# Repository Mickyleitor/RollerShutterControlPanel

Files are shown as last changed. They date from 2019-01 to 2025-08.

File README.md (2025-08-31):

# Roller Shutter Control Panel

Embedded wall panel for motorized shutters over radio; with LCD; buttons; Wi-Fi via ESP8266; clock;
and temperature. Open hardware with 3D-printed parts; off-the-shelf modules; and a PCB using an
ATMega328P plus ESP8266.

<p align="center">
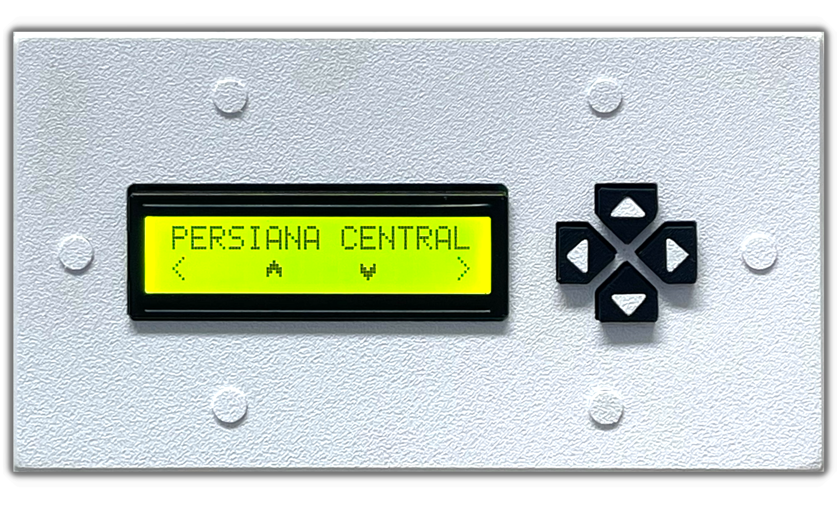
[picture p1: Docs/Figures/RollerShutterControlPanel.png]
  
</p>

## Motivation and origins

Built to stop sunrise from waking me early; first a simple wall controller; then my 2020 Bachelor’s
thesis; now an open build others can replicate; learn from; and adapt. Also a testbed for new ideas.

## Project status; what it does today

Actively used and stable. Local controller for **three** shutters; buttons to move; LCD for time and
date; current temperature from the internet; on-device Wi-Fi setup; ESP8266 firmware updates over
the air. No cloud required.

## Current functionality

- **Three shutters**; Left; Center; Right; actions: Up; Down; Stop at any time.
- **16×2 I²C LCD**; Shutter management, clock on idle and configuration menu.
- **Current temperature**; periodic OpenWeatherMap request; hides value when unavailable.
- **On-device Wi-Fi setup**; scan networks; choose SSID; enable or disable Wi-Fi and OTA;
- **Auto reconnect**; for both wifi attemps and weather requests.
- **Time and timezone editor**; set time and timezone.
- **OTA updates** for the ESP8266 using ArduinoOTA; handled in the background.
- **Buzzer feedback**; adjustable volume; enable or disable; accept and error tones.
- **Debug pages**; soft reset counter; current SSID with link status; device IP.

## Repository layout

```
Docs/                     Documents
├─ Figures/               Diagrams, schematics, screenshots
├─ Files/                 Raw docs (.docx, .pdf, etc.)
└─ Photos/                Prototyping photos

Firmware_Arduino/         Arduino MCU source
Firmware_ESP8266/         ESP8266 source
Firmware_Processing_HCI/  Processing-IDE files

PCB_Design/               KiCAD board files
├─ Libraries/             Custom symbols
└─ Modules/               Footprints & 3D models

3D_Design/                Panel case models
```

## Tools

Free or evaluation to avoid licensing issues:  
• KiCAD; Arduino IDE; Google SketchUp (free); GIMP; Cameo Systems Modeler (evaluation);  
  draw.io (online); VSCode.

## License

CERN Open Hardware Licence.

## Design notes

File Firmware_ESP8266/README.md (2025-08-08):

# Roller Shutter Control Panel — Main CPU (ESP8266)

This serves as the primary CPU for the roller shutter control panel; it uses the [ESP8266]
microcontroller and is programmed using the [Arduino IDE].

## Introduction

This firmware runs on an ESP8266 module and acts as the “brain” of a roller shutter control panel.
It drives a 16x2 I²C LCD; reads panel buttons; and commands three shutters through a radio module
via I²C. When Wi-Fi is enabled it connects as a station; fetches the current temperature and the
timezone shift; keeps the clock in sync; and shows status on the LCD. All common settings can be
changed from the panel; no reflash required.

## Proposed Enhancements

1. **AP fallback for first-time setup.** If repeated station connects fail; bring up a temporary AP
   and a tiny config page; go back to STA when saved.
2. **Location and API key in UI.** Add menu items to edit OpenWeatherMap `lat` and `lon` and rotate
   the API key; mask the key in the UI; store in EEPROM.
3. **HTTPS for the web UI** start with a self-signed cert; allow uploading a new certificate for
   encrypted credentials.
4. **Language option** Keep Spanish strings; add English selection in a simple Language menu.
5. **Update radio-module** Update radio-module firmware from ESP8266; and from the web UI or OTA.
6. **Diagnostics** Optional web pages to visualize additional data when it adds value.

[ESP8266]: https://en.wikipedia.org/wiki/ESP8266
[Arduino IDE]: https://www.arduino.cc/en/Main/Software

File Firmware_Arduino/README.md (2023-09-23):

# Roller Shutter Control Panel Slave CPU

The Roller Shutter Control Panel Slave CPU is a vital component of the larger Domotic Shutter Control System. It operates as an ATmega368P microcontroller, serving as a subordinate CPU within the system.

## Overview

This CPU is dedicated to interfacing with the primary control unit (main CPU) using the I2C communication protocol as the physical layer. However, the communication between the main CPU and the slave CPU relies on the RSCP (Roller Shutter Control Panel) stack protocol. Its primary function is to receive commands and data from the main CPU via the RSCP protocol and execute various control tasks related to roller shutter operation, relay switching, and buzzer control.

## Key Features

- **RSCP Protocol**: The slave CPU communicates with the main CPU using the RSCP (Roller Shutter Control Panel) stack protocol that is implemented on top of the I2C physical layer.

- **Roller Shutter Control**: It possesses the capability to command the movement of roller shutters, including actions such as opening, closing, and stopping.

- **Relay Switching**: The CPU has the capability to control relays, enabling the activation or deactivation of connected devices or circuits.

- **Buzzer Control**: The inclusion of buzzer control functionality allows for audible alerts or notifications.

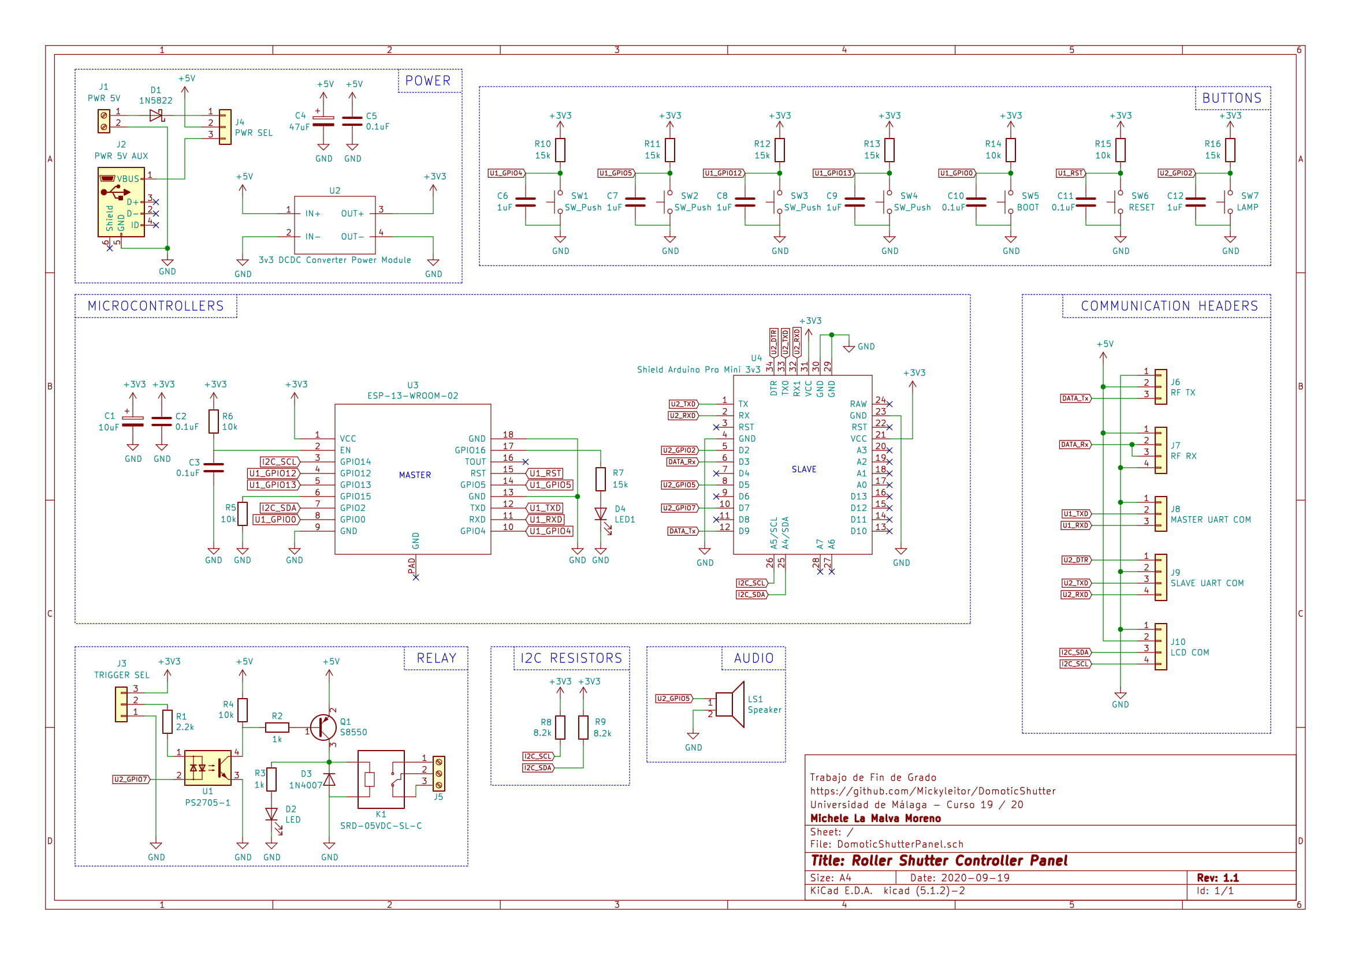
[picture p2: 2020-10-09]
Docs/Figures/RollerShutterControlPanel_Schematic.jpg

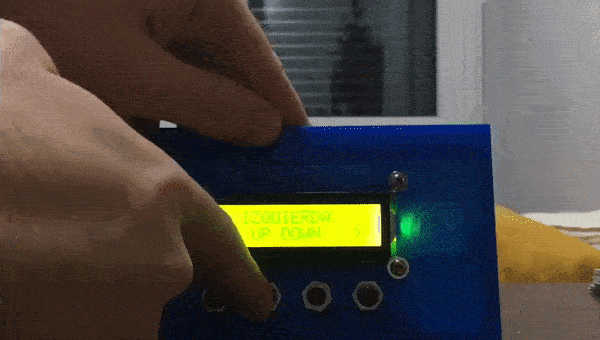
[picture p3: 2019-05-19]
Docs/Photos/Demo2.gif

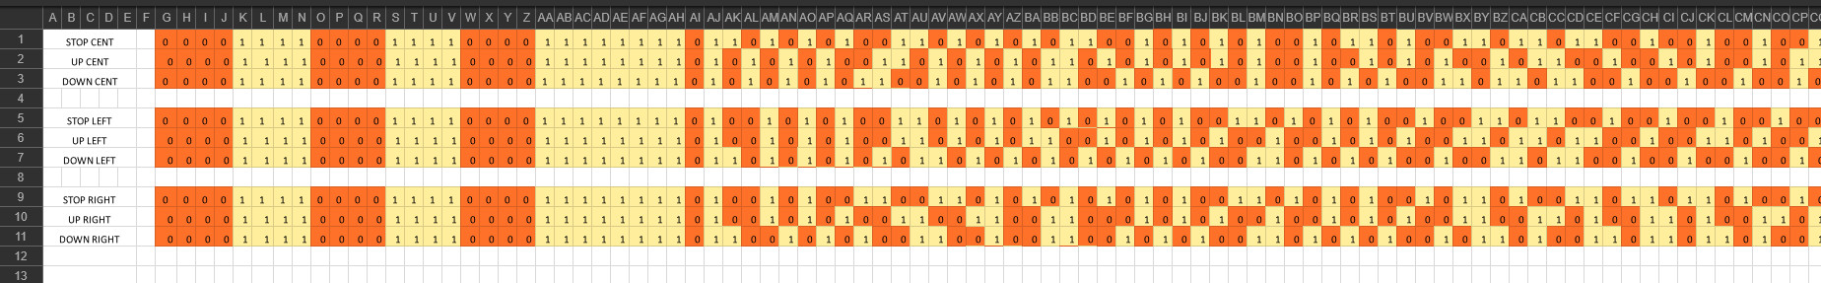
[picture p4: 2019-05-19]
Docs/Photos/Excelmessages.jpg

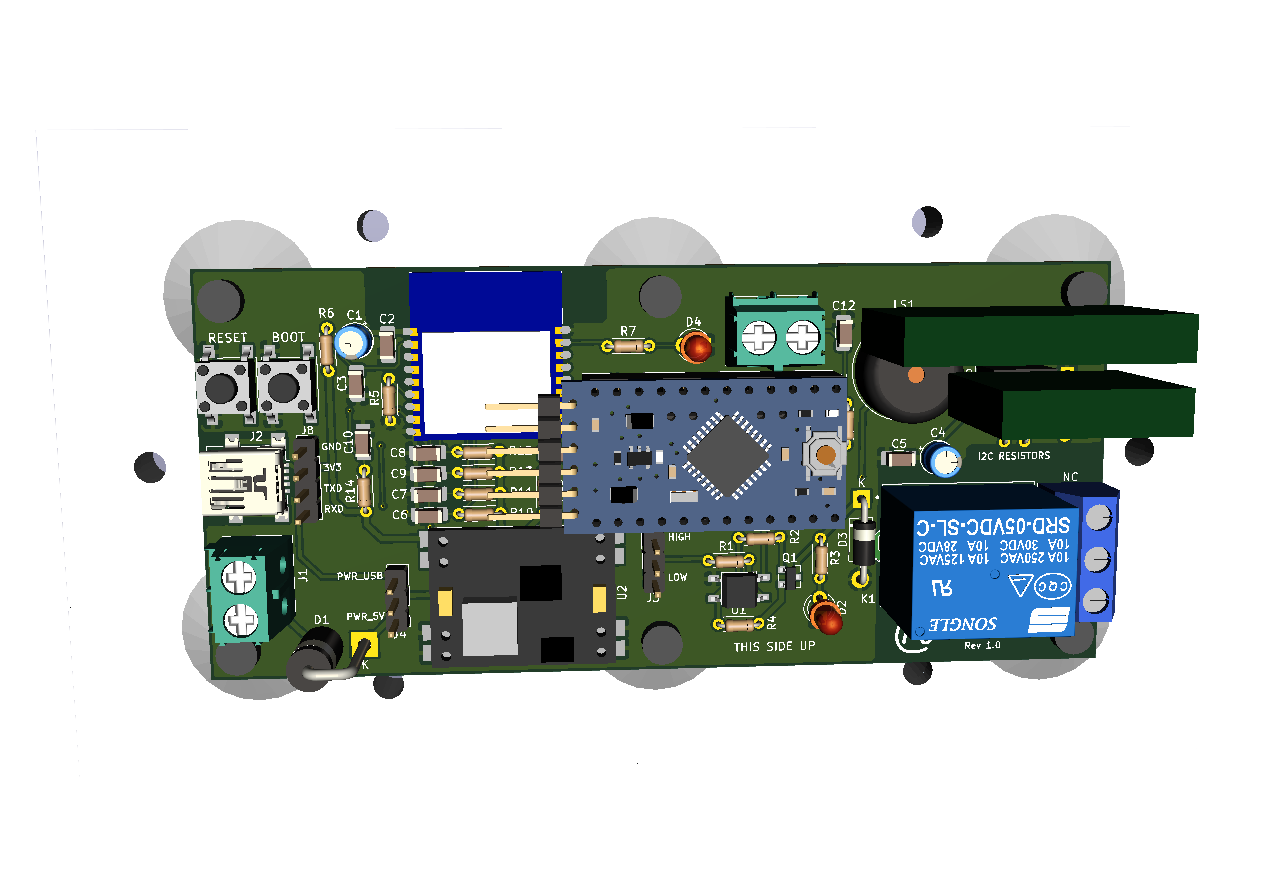
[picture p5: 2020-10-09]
Docs/Figures/RollerShutterControl3D.png

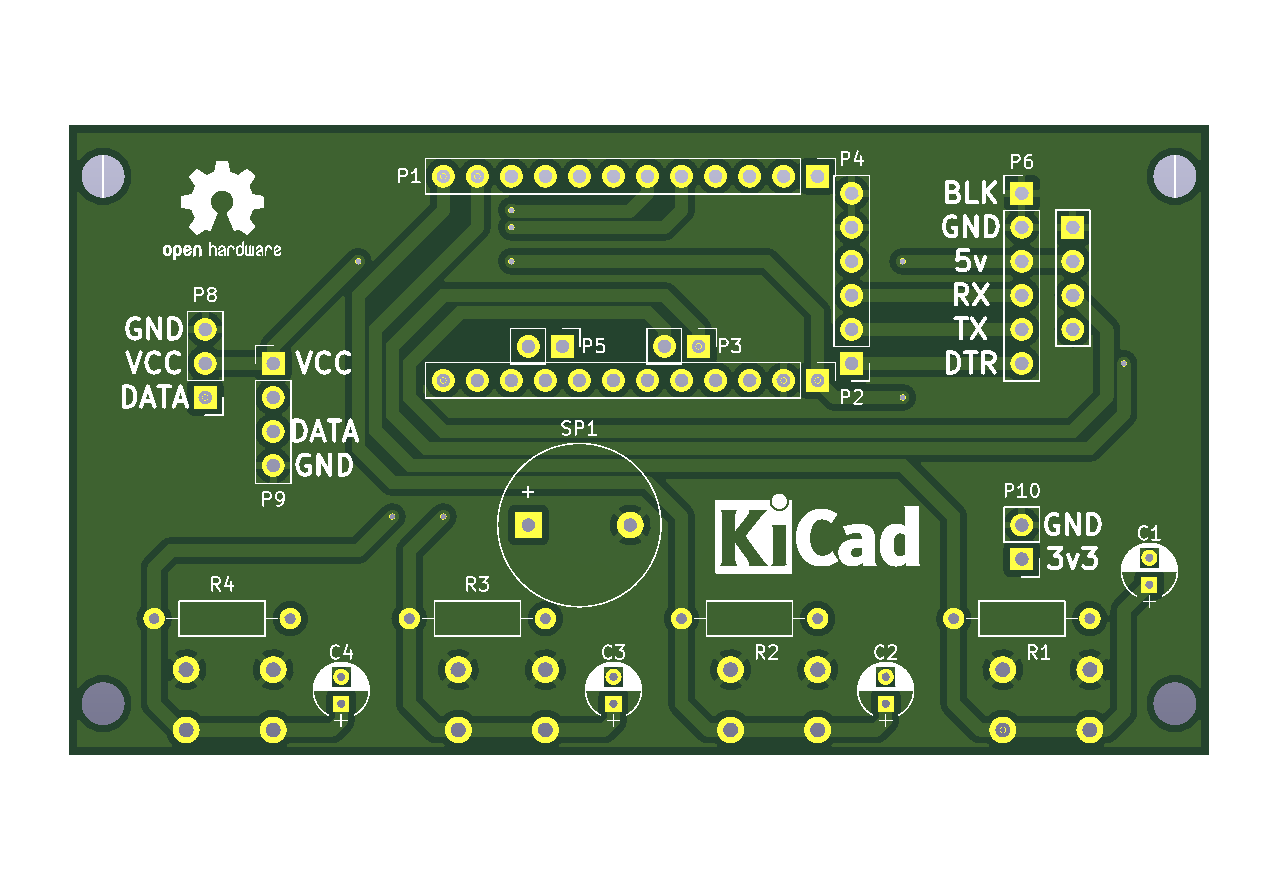
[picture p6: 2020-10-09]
Docs/Figures/RollerShutterControlBoardFront_v1.png

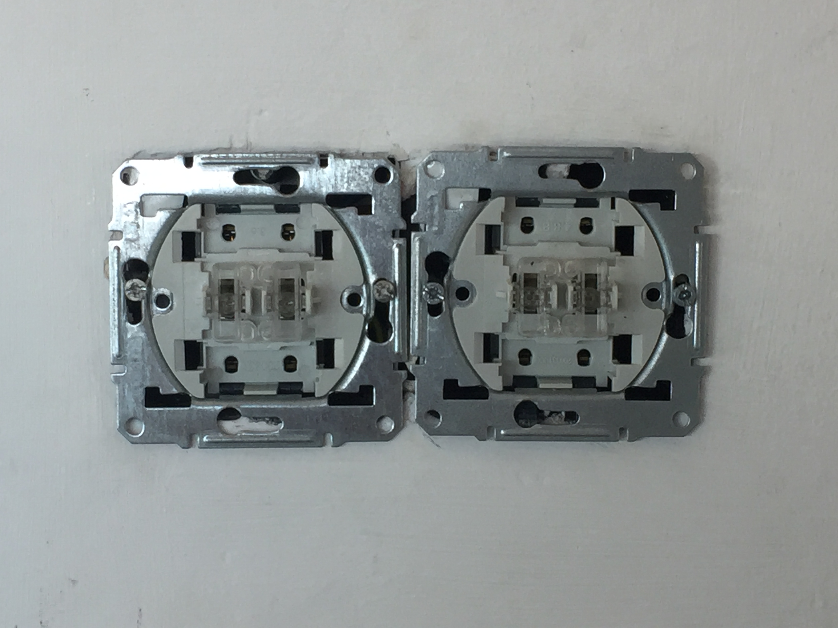
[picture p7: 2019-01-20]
Docs/Photos/EmpotradoPared1.JPG

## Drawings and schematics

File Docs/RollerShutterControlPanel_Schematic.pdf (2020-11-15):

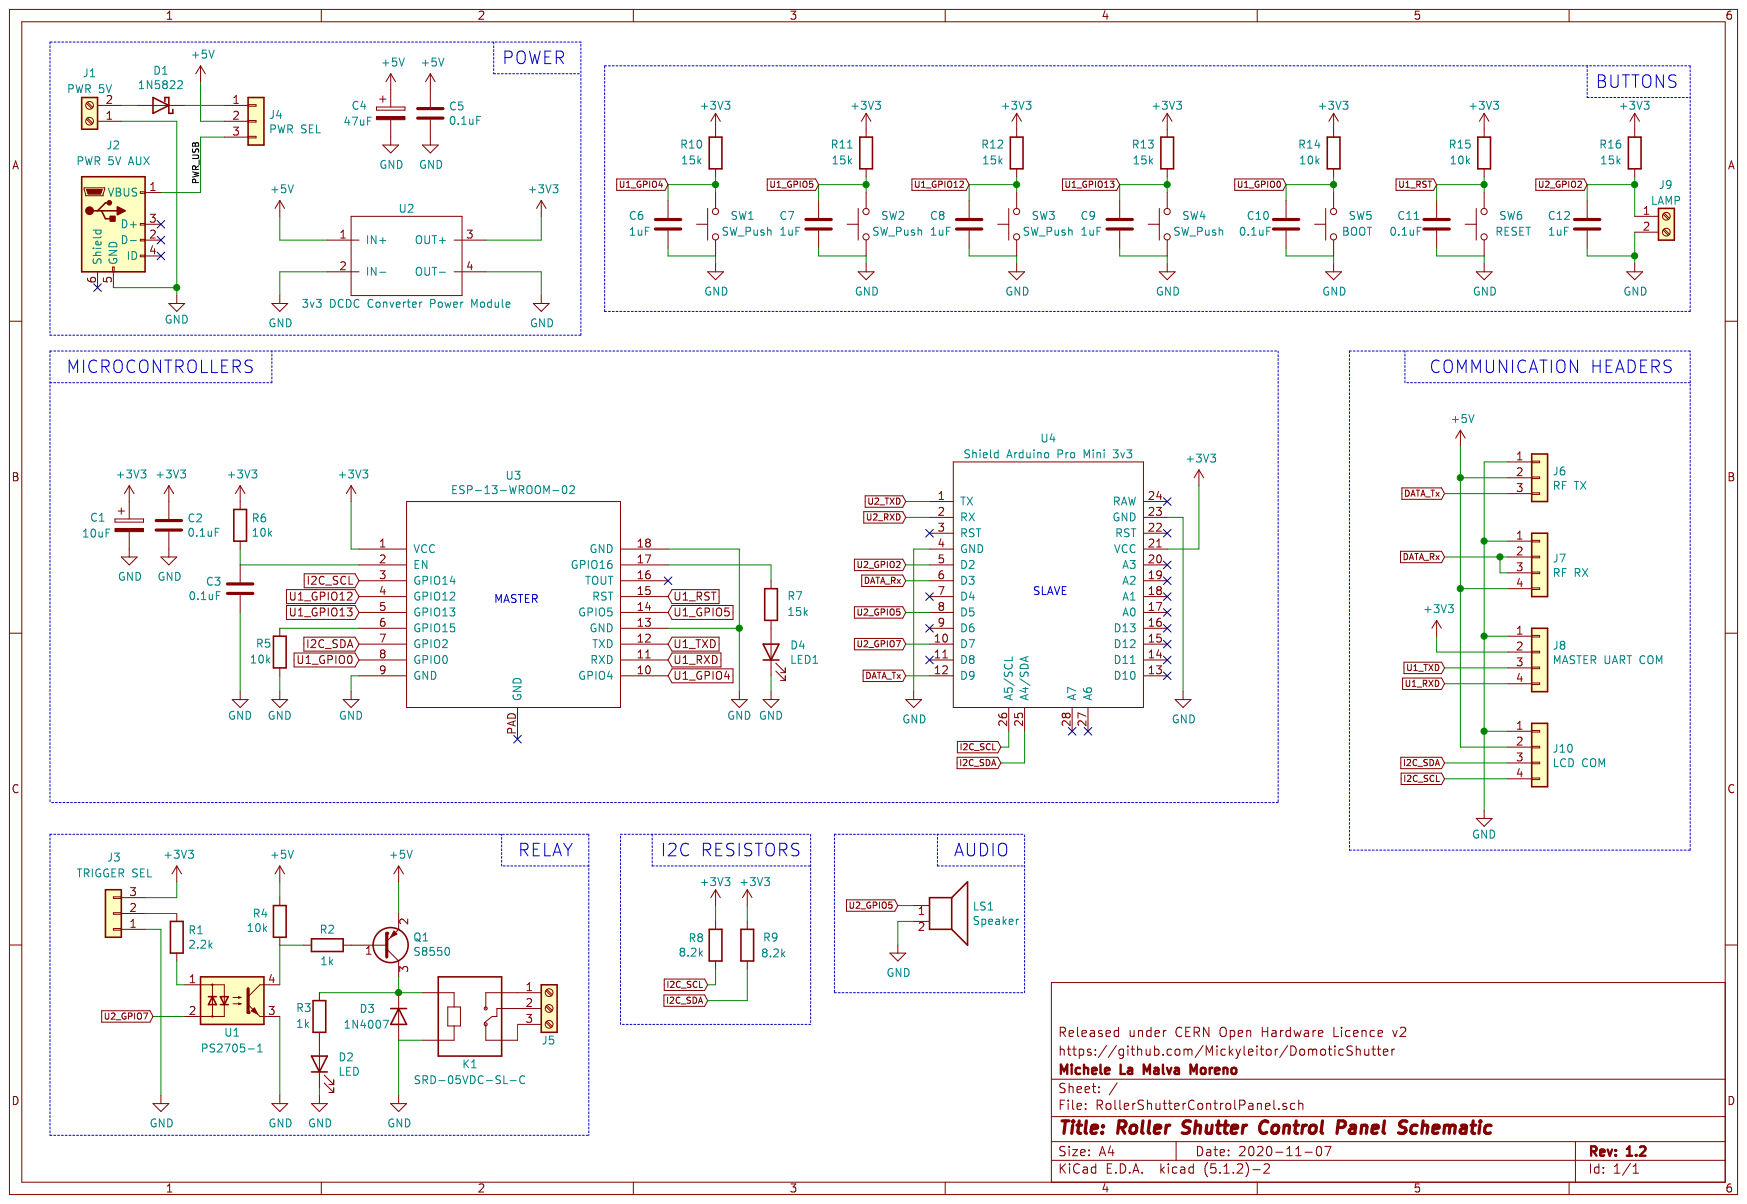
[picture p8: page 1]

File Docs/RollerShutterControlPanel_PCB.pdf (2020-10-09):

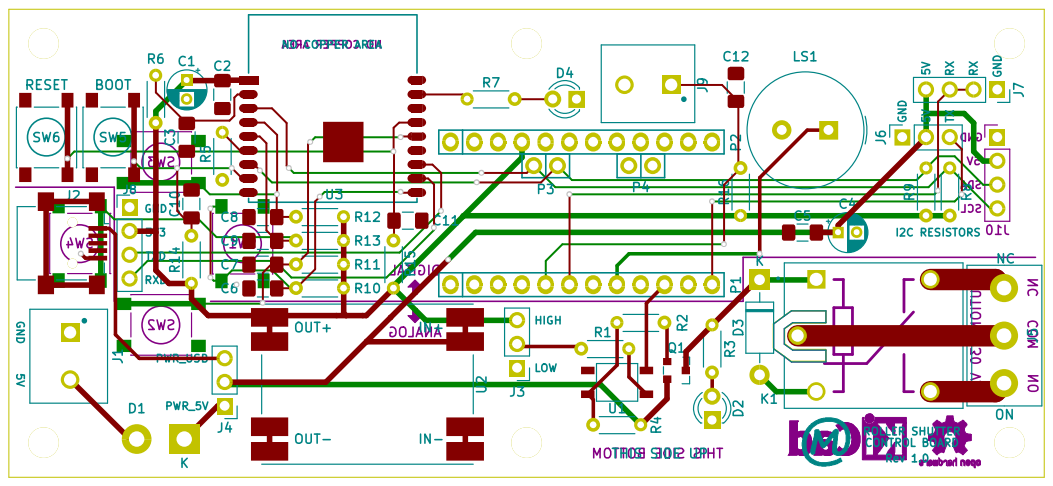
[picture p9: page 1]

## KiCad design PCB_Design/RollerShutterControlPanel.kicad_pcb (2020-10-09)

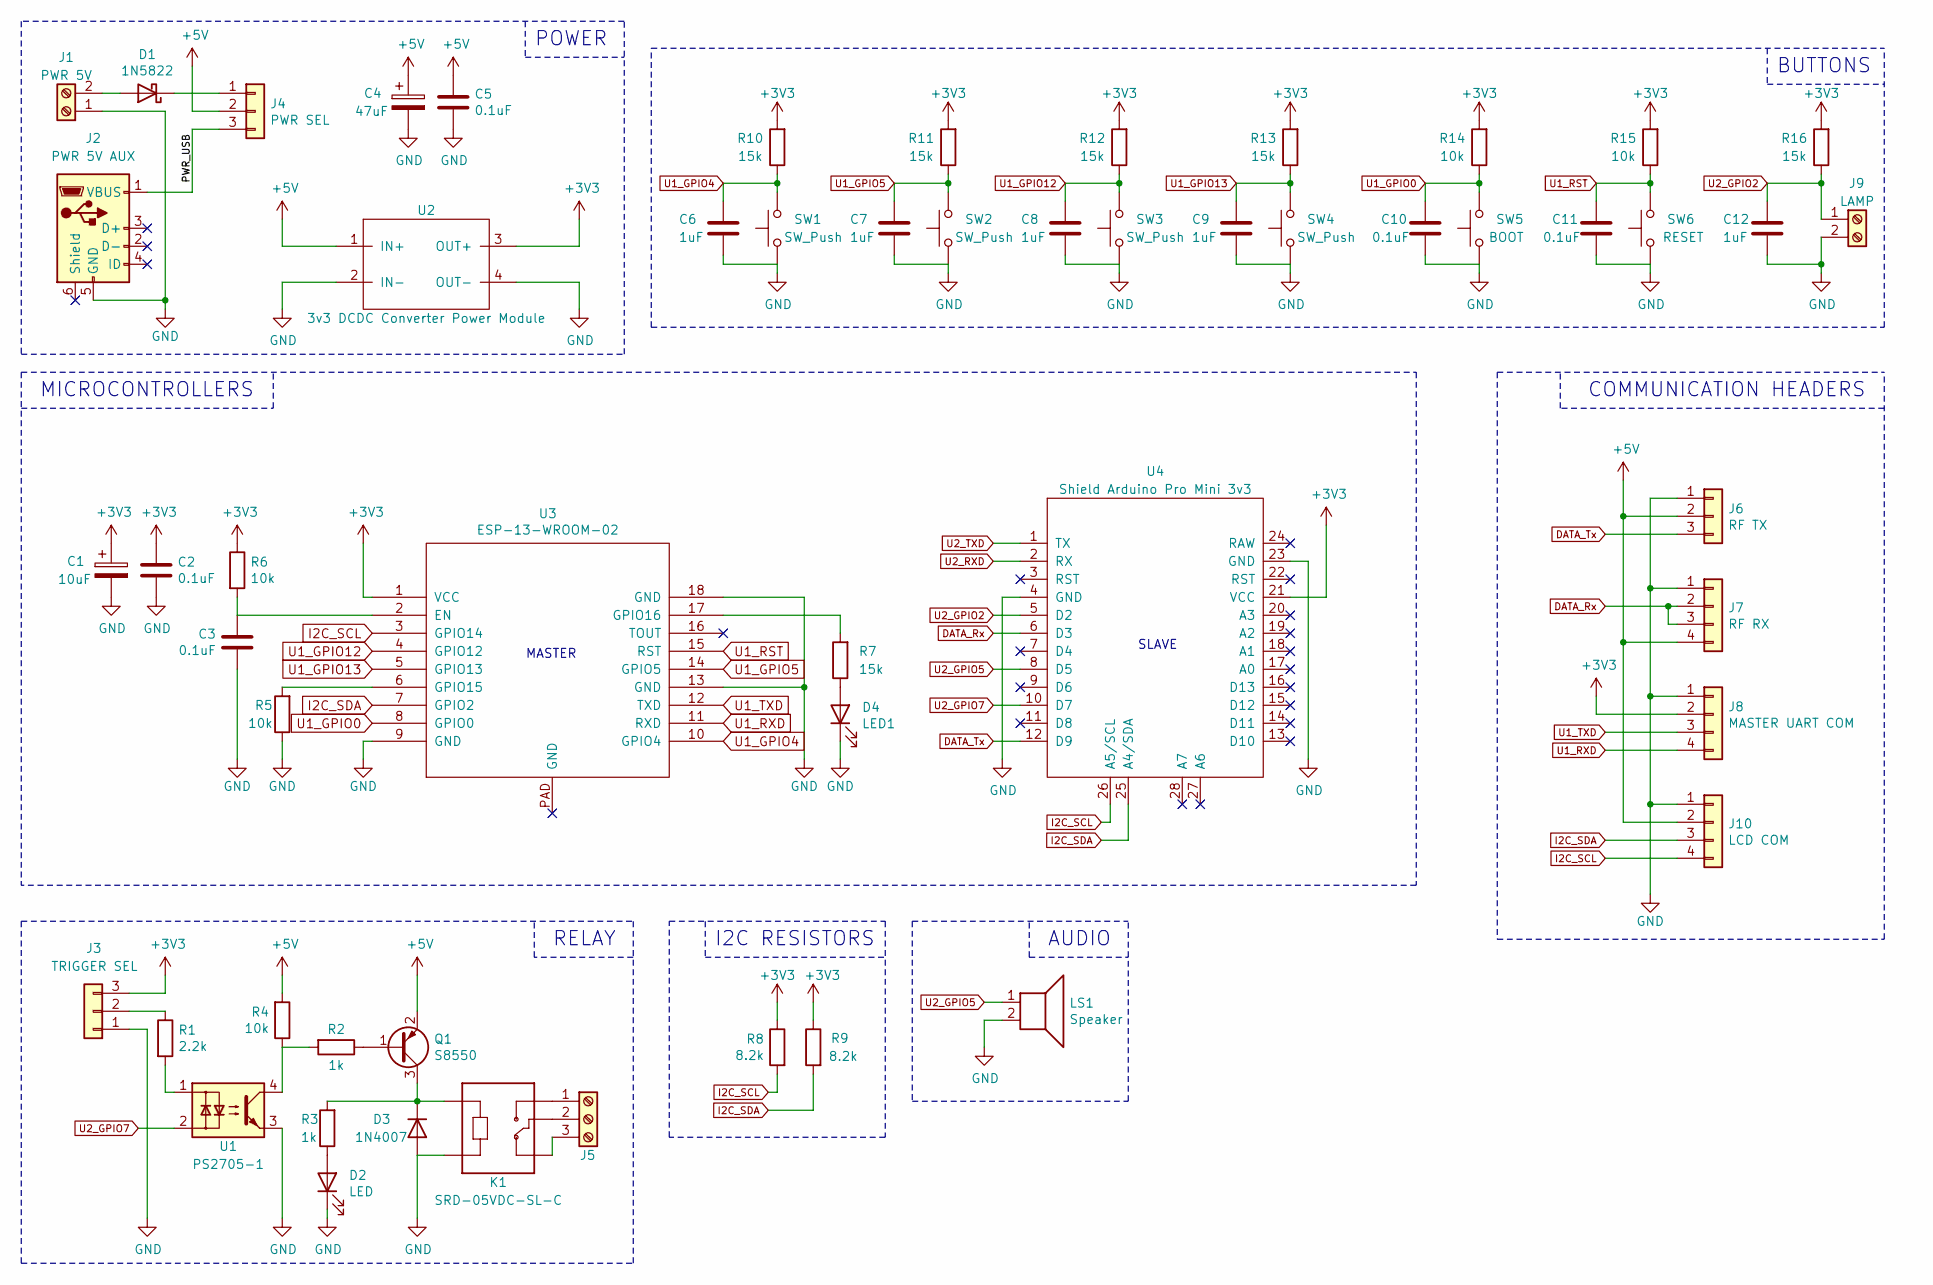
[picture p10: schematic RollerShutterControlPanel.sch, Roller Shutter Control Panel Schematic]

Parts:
C1: 10uF; CP_Radial_D4.0mm_P2.00mm
C2, C3, C5, C10, C11: 0.1uF; C_1206_3216Metric_Pad1.42x1.75mm_HandSolder
C4: 47uF; CP_Radial_D4.0mm_P2.00mm
C6, C7, C8, C9, C12: 1uF; C_1206_3216Metric_Pad1.42x1.75mm_HandSolder
D1: 1N5822; D_DO-201AD_P5.08mm_Vertical_KathodeUp
D2: LED; LED_D3.0mm
D3: 1N4007; D_DO-41_SOD81_P10.16mm_Horizontal
D4: LED1; LED_D3.0mm
J1: PWR 5V; PHOENIX_1935161
J2: PWR 5V AUX; USB_Mini-B_Lumberg_2486_01_Horizontal
J3: TRIGGER SEL; PinHeader_1x03_P2.54mm_Vertical
J4: PWR SEL; PinHeader_1x03_P2.54mm_Vertical
J5: Screw_Terminal_01x03; ScrewTerminal_01X03_5mm
J6: RF TX; PinSocket_1x03_P2.54mm_Vertical
J7: RF RX; PinSocket_1x04_P2.54mm_Vertical
J8: MASTER UART COM; PinHeader_1x04_P2.54mm_Vertical
J9: LAMP; PHOENIX_1935161
J10: LCD COM; PinSocket_1x04_P2.54mm_Vertical
K1: SRD-05VDC-SL-C; RELAY_SRD-05VDC-SL-C
LS1: Speaker; Buzzer_TDK_PS1240P02BT_D12.2mm_H6.5mm
Q1: S8550; SOT-23_S8550
R1: 2.2k; R_Axial_DIN0204_L3.6mm_D1.6mm_P5.08mm_Horizontal
R2, R3: 1k; R_Axial_DIN0204_L3.6mm_D1.6mm_P5.08mm_Horizontal
R4, R5, R6, R14, R15: 10k; R_Axial_DIN0204_L3.6mm_D1.6mm_P5.08mm_Horizontal
R7, R10, R11, R12, R13, R16: 15k; R_Axial_DIN0204_L3.6mm_D1.6mm_P5.08mm_Horizontal
R8, R9: 8.2k; R_Axial_DIN0204_L3.6mm_D1.6mm_P5.08mm_Horizontal
SW1, SW2, SW3, SW4: SW_Push; SW_Push_1P1T_NO_6x6mm_H5mm
SW5: BOOT; SW_Push_1P1T_NO_6x6mm_H5mm
SW6: RESET; SW_Push_1P1T_NO_6x6mm_H5mm
U1: PS2705-1; PS2705-1-F3
U2: 3v3 DCDC Converter Power Module; DCDC_3v3_PowerModule
U3: ESP-13-WROOM-02
U4: Shield Arduino Pro Mini 3v3; Socket_Strip_Arduino_MiniPro

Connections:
+3V3: C1.1, C2.1, J3.3, J8.2, R6.1, R8.1, R9.1, R10.2, R11.2, R12.2, R13.2, R14.2, R15.2, R16.2, U2.3 (OUT+), U3.1 (VCC), U4.21 (VCC)
+5V: C4.1, C5.1, J4.2, J6.2, J7.4, J10.2, Q1.2 (E), R4.2, U2.1 (IN+)
/PWR_USB: J2.1 (VBUS), J4.3
DATA_Rx: J7.2, J7.3, U4.6 (D3)
DATA_Tx: J6.3, U4.12 (D9)
GND: C1.2, C2.2, C3.2, C4.2, C5.2, C6.1, C7.1, C8.1, C9.1, C10.1, C11.1, C12.1, D2.1 (K), D3.2 (A), D4.1 (K), J1.1, J2.5 (GND), J3.1, J6.1, J7.1, J8.1, J9.2, J10.1, K1.A2, LS1.2, R5.1, SW1.1, SW2.1, SW3.1, SW4.1, SW5.1, SW6.1, U1.3, U2.2 (IN-), U2.4 (OUT-), U3.9 (GND), U3.13 (GND), U3.18 (GND), U4.4 (GND), U4.23 (GND)
I2C_SCL: J10.4, R8.2, U3.3 (GPIO14), U4.26 (A5/SCL)
I2C_SDA: J10.3, R9.2, U3.7 (GPIO2), U4.25 (A4/SDA)
unnamed: C3.1, R6.2, U3.2 (EN)
unnamed: D1.1 (K), J4.1
unnamed: D1.2 (A), J1.2
unnamed: D2.2 (A), R3.1
unnamed: D3.1 (K), K1.A1, Q1.3 (C), R3.2
unnamed: D4.2 (A), R7.1
unnamed: J3.2, R1.1
unnamed: J5.1, K1.NO
unnamed: J5.2, K1.COM
unnamed: J5.3, K1.NC
unnamed: Q1.1 (B), R2.1
unnamed: R1.2, U1.1
unnamed: R2.2, R4.1, U1.4
unnamed: R5.2, U3.6 (GPIO15)
unnamed: R7.2, U3.17 (GPIO16)
U1_GPIO0: C10.2, R14.1, SW5.2, U3.8 (GPIO0)
U1_GPIO4: C6.2, R10.1, SW1.2, U3.10 (GPIO4)
U1_GPIO5: C7.2, R11.1, SW2.2, U3.14 (GPIO5)
U1_GPIO12: C8.2, R12.1, SW3.2, U3.4 (GPIO12)
U1_GPIO13: C9.2, R13.1, SW4.2, U3.5 (GPIO13)
U1_RST: C11.2, R15.1, SW6.2, U3.15 (RST)
U1_RXD: J8.4, U3.11 (RXD)
U1_TXD: J8.3, U3.12 (TXD)
U2_GPIO2: C12.2, J9.1, R16.1, U4.5 (D2)
U2_GPIO5: LS1.1, U4.8 (D5)
U2_GPIO7: U1.2, U4.10 (D7)
U2_RXD: U4.2 (RX)
U2_TXD: U4.1 (TX)

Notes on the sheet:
I2C RESISTORS
AUDIO
SLAVE
MASTER
COMMUNICATION HEADERS
RELAY
MICROCONTROLLERS
BUTTONS
POWER

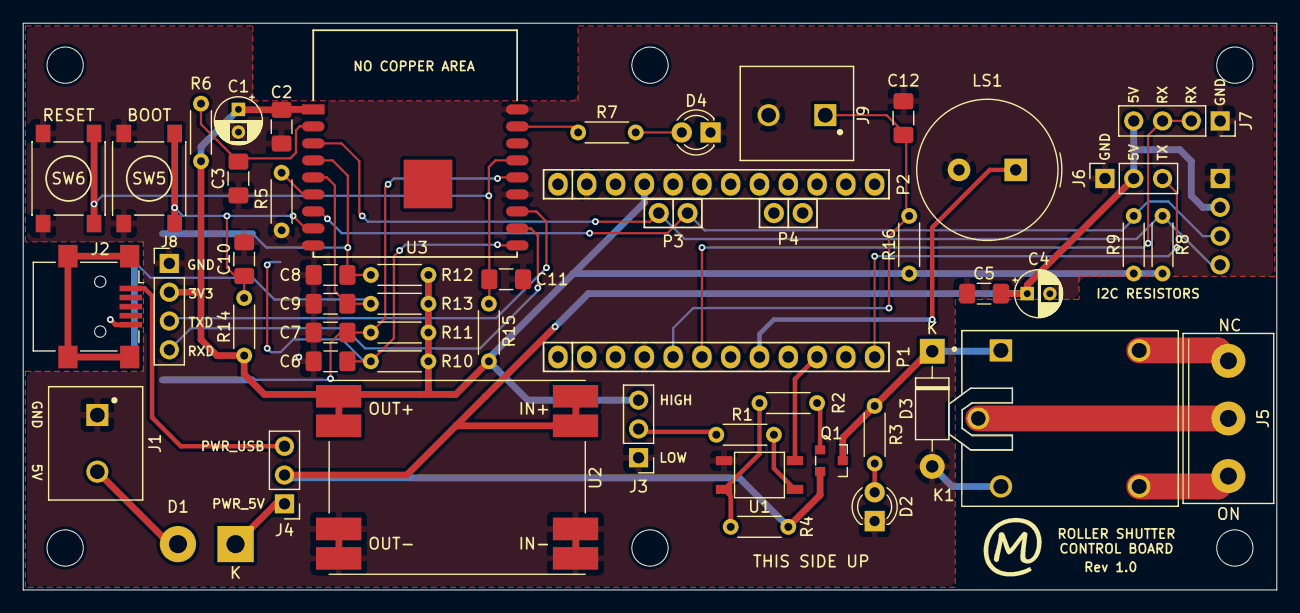
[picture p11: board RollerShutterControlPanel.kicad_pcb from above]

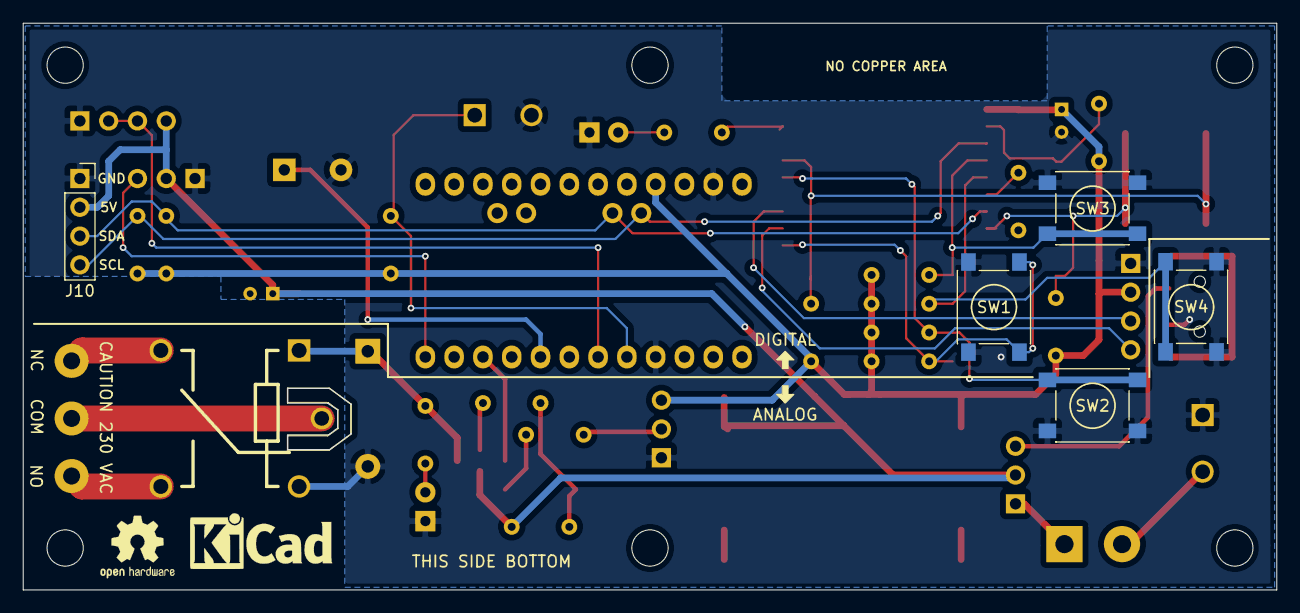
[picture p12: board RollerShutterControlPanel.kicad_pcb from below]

Board: 2 copper layers, 110.6 x 50.0 mm, 56 parts (6 on the bottom side), 34 nets.

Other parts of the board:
Carcasa: Carcasa

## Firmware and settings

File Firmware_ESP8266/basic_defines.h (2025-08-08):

#pragma once

#define SLAVE_I2C_ADDRESS                                                 (0x08)
#define LCD_I2C_ADDRESS                                                   (0x3F)

#define DEFAULT_BUZZER_ENABLED                                            false
#define DEFAULT_BUZZER_VOLUME                                             (4000)
#define DEFAULT_STA_SSID                                             "YOUR_SSID"
#define DEFAULT_STA_PASSWORD                                     "YOUR_PASSWORD"
#define DEFAULT_WIFI_ENABLED                                              false
#define DEFAULT_WIFI_OTA_ENABLED                                          false

#define OPENWEATHERMAP_HOST                             "api.openweathermap.org"
#define OPENWEATHERMAP_PORT                                                 (80)
#define DEFAULT_OPENWEATHERMAP_APPID                                          ""
#define DEFAULT_OPENWEATHERMAP_LOCATION_LAT                                  (0)
#define DEFAULT_OPENWEATHERMAP_LOCATION_LON                                  (0)

#define OPENWEATHERMAP_HTTP_REQUEST(appid, lat, long) \
    "GET /data/2.5/weather?lat=" + \
    String(lat) + \
    "&lon=" + \
    String(long) + \
    "&appid=" + \
    String(appid) + \
    "&units=metric&lang=es HTTP/1.0"

enum SystemState {
    SYSTEM_STATE_ENTERING_IDLE,
    SYSTEM_STATE_IDLING,
    SYSTEM_STATE_WAKEUP,
    SYSTEM_STATE_MENU,
};

typedef uint8_t SystemState_t;

enum seleccionMenu {
    SELECCION_MENU_RELOJ,
    SELECCION_MENU_PERSIANA_IZQUIERDA,
    SELECCION_MENU_PERSIANA_CENTRAL,
    SELECCION_MENU_PERSIANA_DERECHA,

    // Starting from here, if there is a button timeout when some menu below is displayed,
    // it will return to the default shutter menu when we wake up again.
    SELECCION_MENU_CONFIG,
    SELECCION_MENU_CONFIG_FECHA_HORA,
    SELECCION_MENU_CONFIG_FECHA_HORA_AJUSTE,
    SELECCION_MENU_CONFIG_ZONA_HORARIA_AJUSTE,
    SELECCION_MENU_CONFIG_VOLUMEN,
    SELECCION_MENU_CONFIG_VOLUMEN_AJUSTE,
    SELECCION_MENU_CONFIG_DEBUG,
    SELECCION_MENU_CONFIG_DEBUG_SOFT_RST_COUNT,
    SELECCION_MENU_CONFIG_DEBUG_WIFI_SSID,
    SELECCION_MENU_CONFIG_DEBUG_WIFI_IP,
    SELECCION_MENU_CONFIG_WIFI,
    SELECCION_MENU_CONFIG_WIFI_HABILITAR,
    SELECCION_MENU_CONFIG_WIFI_OTA_HABILITAR,
    SELECCION_MENU_CONFIG_WIFI_SSID,
    SELECCION_MENU_CONFIG_WIFI_PASSWORD,
    SELECCION_MENU_CONFIG_WIFI_RESULTADO,

    SELECCION_MENU_MAX
};

typedef uint8_t seleccionMenu_t;

// This macro is used to convert the enum to the index of the array
#define SELECCION_MENU_PERSIANA_TO_INDEX(x)     ((x - SELECCION_MENU_RELOJ) - 1)

// Default selection menu. This can't be the SELECCION_MENU_RELOJ
#define DEFAULT_SELECTION_MENU                 (SELECCION_MENU_PERSIANA_CENTRAL)

enum ButtonStatus {
    BUTTON_STATUS_NONE,
    BUTTON_STATUS_LEFT,
    BUTTON_STATUS_UP,
    BUTTON_STATUS_DOWN,
    BUTTON_STATUS_RIGHT
};

enum ShutterStatus {
    SHUTTER_STATUS_STOPPED,
    SHUTTER_STATUS_MOVING_UP,
    SHUTTER_STATUS_MOVING_DOWN,
};

typedef uint8_t ShutterStatus_t;

#define NUMBER_OF_SHUTTERS                                                   (3)

struct ShutterParameters {
    ShutterStatus_t status;
    unsigned long lastUpdate;
};

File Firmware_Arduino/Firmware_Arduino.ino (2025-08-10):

/**
 * @file Domotic Shutter sketch by Mickyleitor
 * @brief This sketch is in development and uses ATmega368P.
 *
 * @details
 * Libraries used and need to be installed from Arduino IDE:
 * - Low-Power by rocketscream/ version 1.6.0: https://github.com/rocketscream/Low-Power
 *
 * Current protocol for I2C messages with master is addressed by RSCP (Roller Shutter Control Panel)
 * protocol.
 */

#include <Wire.h>

#include "LowPower.h"
#include "TaskBuffer.h"
#include "basic_defines.h"
#include "moduleConfigs/radioProtocolConfig.h"
#include "remote.h"
#include "rscpProtocol/rscpProtocol.h"

/**
 * @enum SystemState
 * @brief Enumeration of system states.
 */
enum SystemState {
    LOW_POWER,   ///< Low power state
    IDLE,        ///< Idle state
    RUNNING,     ///< Running state
    SWITCH_RELAY ///< Switch relay state
};

SystemState currentSystemState = RUNNING;

bool isBuzzerRunning = false;

/**
 * @brief Setup function for Arduino.
 */
void setup() {
    pinMode(PIN_BUZZER, OUTPUT);
    pinMode(RADIOPROTOCOL_PINNUMBER_RF_TX, INPUT);
    pinMode(RADIOPROTOCOL_PINNUMBER_RF_RX, INPUT);
    pinMode(PIN_RELAY, OUTPUT);
    initButtonsFunction();

    Serial.begin(115200);
    Serial.println("Slave initialized");

    Wire.begin(I2C_SLAVE_ADDRESS);
    Wire.onReceive(receiveEvent);
    Wire.onRequest(requestEvent);

    currentSystemState = RUNNING;
}

/**
 * @brief Main loop for Arduino.
 */
void loop() {
    static uint32_t timeout_ms;
    rscpTaskType task;

    switch (currentSystemState) {
        case LOW_POWER: {
            Serial.println("Entering low-power mode...");
            Serial.flush();
            LowPower.idle(
                    SLEEP_FOREVER,
                    ADC_OFF,
                    TIMER2_OFF,
                    TIMER1_ON,
                    TIMER0_OFF,
                    SPI_OFF,
                    USART0_OFF,
                    TWI_ON);
            currentSystemState = RUNNING;
            break;
        }
        case SWITCH_RELAY: {
            digitalWrite(PIN_RELAY, digitalRead(PIN_BUTTON_USER));
            Serial.println("Button pressed");
            currentSystemState = RUNNING;
            break;
        }
        case RUNNING: {
            if (peekTaskFromBuffer(&task) < 0) {
                timeout_ms         = millis();
                currentSystemState = IDLE;
                break;
            }

            bool removeTask = true;

            switch (task.command) {
                case RSCP_CMD_SET_SHUTTER_ACTION: {
                    struct RSCP_Arg_rollershutter* arg = (struct RSCP_Arg_rollershutter*)task.arg;
                    if (arg->shutter <= 2 && arg->action <= 3) {
                        for (int retries = 0; retries < arg->retries; retries++) {
                            sendCommand(arg->shutter, arg->action - 1);
                        }
                    }
                    break;
                }
                case RSCP_CMD_SET_SWITCH_RELAY: {
                    struct RSCP_Arg_switchrelay* arg = (struct RSCP_Arg_switchrelay*)task.arg;
                    digitalWrite(PIN_RELAY, (arg->status == RSCP_DEF_SWITCH_RELAY_ON) ? HIGH : LOW);
                    break;
                }
                case RSCP_CMD_SET_BUZZER_ACTION: {
                    struct RSCP_Arg_buzzer_action* arg = (struct RSCP_Arg_buzzer_action*)task.arg;
                    switch (arg->action) {
                        case RSCP_DEF_BUZZER_ACTION_ON: {
                            removeTask = false;
                            if (isBuzzerRunning) {
                                if ((millis() - timeout_ms) > arg->duration_ms) {
                                    noTone(PIN_BUZZER);
                                    isBuzzerRunning = false;
                                    removeTask      = true;
                                    break;
                                }
                                break;
                            }
                            tone(PIN_BUZZER, arg->volume, arg->duration_ms);
                            timeout_ms      = millis();
                            isBuzzerRunning = true;
                            break;
                        }
                        case RSCP_DEF_BUZZER_ACTION_OFF: {
                            noTone(PIN_BUZZER);
                            isBuzzerRunning = false;
                            break;
                        }
                    }
                    break;
                }
            }

            if (removeTask) {
                popTaskFromBuffer(&task);
            }

            break;
        }
        case IDLE: {
            if ((millis() - timeout_ms) > IDLE_TIMEOUT_MS) {
                currentSystemState = LOW_POWER;
            }
            break;
        }
    }
}

/**
 * @brief Function that executes whenever data is received from the master.
 *
 * @param howMany Number of bytes received.
 */
void receiveEvent(int howMany) {
    // Read all bytes from I2C later in requestEvent
}

/**
 * @brief Function that executes whenever data is requested by the master.
 */
void requestEvent() {
    int8_t err;
    if ((err = rscpHandle(I2C_TIMEOUT_MS)) < 0) {
        Serial.println("[ERROR] rscpHandle: " + String(err));
    }
    currentSystemState = RUNNING;
}

/**
 * @brief Interrupt service routine for the button.
 */
void isrButton() {
    // Detach the interrupt to avoid retriggering during debounce
    detachInterrupt(digitalPinToInterrupt(PIN_BUTTON_USER));

    // Reset Timer 1 counter to 0 and start counting (CTC mode, scale to clock / 256)
    TCNT1  = 0;
    TCCR1B = bit(WGM12) | bit(CS12);
}

/**
 * @brief Interrupt service routine for Timer 1 Compare A Match.
 */
ISR(TIMER1_COMPA_vect) {
    currentSystemState = SWITCH_RELAY;

    // Stop Timer 1 (clear prescaler) and reattach the button interrupt on changing edge
    TCCR1B = 0;
    attachInterrupt(digitalPinToInterrupt(PIN_BUTTON_USER), isrButton, CHANGE);
}

/**
 * @brief Initialize button functions.
 */
void initButtonsFunction() {
    pinMode(PIN_BUTTON_USER, INPUT_PULLUP);
    attachInterrupt(digitalPinToInterrupt(PIN_BUTTON_USER), isrButton, CHANGE);

    // Set up Timer 1 for debounce
    TCCR1A = 0; // Normal operation
    TCCR1B = 0; // Stop the timer initially

    // Calculate the compare A register value for debounce time
    uint32_t debounce_cycles = (F_CPU / (256UL * 2 * 1000));
    OCR1A                    = (debounce_cycles * DEBOUNCE_TIME_MILLIS) - 1;

    // Enable the interrupt on Compare A Match (Timer 1)
    TIMSK1 = bit(OCIE1A);
}

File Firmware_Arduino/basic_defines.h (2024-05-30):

#pragma once

/**
 * @file basic_defines.h
 * @brief Contains various macros and definitions used in the project.
 */

// General macros

/** @brief Timeout value for entering idle state in milliseconds. */
#define IDLE_TIMEOUT_MS                                                  (10000)

/** @brief Timeout value for I2C communication in milliseconds. */
#define I2C_TIMEOUT_MS                                                    (1000)

// Macros for PIN and PORTs

/** @brief Pin number for the user button. */
#define PIN_BUTTON_USER                                                      (2)

/** @brief Debounce time for button presses in milliseconds. */
#define DEBOUNCE_TIME_MILLIS                                               (100)

// Buzzer

/** @brief Pin number for the buzzer. */
#define PIN_BUZZER                                                           (5)

// Relay

/** @brief Pin number for the relay. */
#define PIN_RELAY                                                            (7)

/** @brief Pin number for I2C SCL. */
#define PIN_I2C_SCL                                                         (A5)

/** @brief Pin number for I2C SDA. */
#define PIN_I2C_SDA                                                         (A4)

// Macros for buzzer volume selections

/** @brief Low volume setting for the buzzer. */
#define BUZZER_LOW_VOLUME                                                (17000)

/** @brief Medium volume setting for the buzzer. */
#define BUZZER_MEDIUM_VOLUME                                               (300)

/** @brief High volume setting for the buzzer. */
#define BUZZER_HIGH_VOLUME                                                (5000)

// Macros for LCD handing

/** @brief I2C slave address for LCD communication. */
#define I2C_SLAVE_ADDRESS                                                    (8)

/**
 * @brief Structure to define an RSCP task.
 */
typedef struct rscpTaskDef {
    uint8_t command;   /**< RSCP command. */
    uint8_t arg[64];   /**< Argument data. */
    uint8_t argLength; /**< Length of the argument data. */
} rscpTaskType;

/** @brief Array to store RSCP tasks. */
rscpTaskType _rscpTasks[4];

/** @brief Number of RSCP tasks in the array. */
uint8_t _rscpTaskCount = 0;

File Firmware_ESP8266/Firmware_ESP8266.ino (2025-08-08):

// Domotic Shutter sketch master by Mickyleitor
// This sketch is in development and uses ESP13-WROOM-02.
//
// Libraries used and need to be installed from Arduino IDE
// - Shield manager ESP8266 by ESP8266 Community version 3.1.2 :
// http://arduino.esp8266.com/stable/package_esp8266com_index.json
// - NTPClient by Fabrice Weinberg 3.2.0 : https://github.com/arduino-libraries/NTPClient
// - LiquidCrystal_PCF8574 by mathertel 2.2.0  : https://github.com/mathertel/LiquidCrystal_PCF8574

#include "EEPROM_Utils.h"
#include "ESP8266_Utils.h"
#include "ShutterManager.h"
#include "Slave_Utils.h"
#include "basic_defines.h"
#include "buttons.h"
#include "error.h"
#include "lcd.h"
#include "persistentVars.h"
#include "rscpProtocol/rscpProtocol.h"
#include "rtcTime.h"

static SystemState_t _SystemState     = SYSTEM_STATE_ENTERING_IDLE;
static seleccionMenu_t _seleccionMenu = DEFAULT_SELECTION_MENU;

void systemStateGoToIdle(void) {
    if (_seleccionMenu <= SELECCION_MENU_CONFIG) {
        _SystemState = SYSTEM_STATE_ENTERING_IDLE;
    }
}

void setup() {
    Serial.begin(115200);
    Serial.println();
    Serial.println("ESP8266 Roller Shutter Control Panel");

    EEPROM_Begin(&settings);
    persistentVars_init();
    rtc_init();

    if (!pantalla_iniciar(10000)) {
        errorHandler(FATAL_ERROR_CODE_LCD_INIT_FAILED);
    }
    pantalla_encenderBrillo();
    pantalla_sendLcdBuffer("    INICIANDO   PANEL DE CONTROL");
    // We wait a bit just in case we just powered on the whole
    // device, sometimes the power is still not enough at this point.
    delay(2000);
    initButtonsFunction();
    checkSlaveConnection();
    buzzer_init();
}

void loop() {
    switch (_SystemState) {
        case SYSTEM_STATE_ENTERING_IDLE: {
            pantalla_apagarBrillo();
            // On entering idle, if menu is beyond info,
            // reset to default when we wake up again.
            if (_seleccionMenu >= SELECCION_MENU_CONFIG) {
                _seleccionMenu = DEFAULT_SELECTION_MENU;
            }
            pantalla_actualizar(true, SELECCION_MENU_RELOJ);
            _SystemState = SYSTEM_STATE_IDLING;
            break;
        }
        case SYSTEM_STATE_IDLING: {
            if (buttonPressed() != BUTTON_STATUS_NONE) {
                _SystemState = SYSTEM_STATE_WAKEUP;
            } else {
                pantalla_actualizar(true, _seleccionMenu);
            }
            break;
        }
        case SYSTEM_STATE_WAKEUP:
            pantalla_encenderBrillo();
            _SystemState = SYSTEM_STATE_MENU;
            break;
        case SYSTEM_STATE_MENU: {
            pantalla_handleButtonInMenu(&_seleccionMenu, buttonPressed(), buttonHolding());
            pantalla_actualizar(false, _seleccionMenu);
            break;
        }
    }
    rtc_handler();
    buzzer_handler();
    shutterHandler();
    EEPROM_Handler();
    Wifi_handler(_seleccionMenu > SELECCION_MENU_CONFIG);

    static Settings previousSettings;
    if (memcmp(&settings, &previousSettings, sizeof(Settings)) != 0) {
        Serial.println("Cambio de configuracion de settings detectado.");
        Serial.print("Habilitado: ");
        Serial.println(settings.wifiSettings.wifi_enabled ? "Si" : "No");
        Serial.print("OTA: ");
        Serial.println(settings.wifiSettings.ota_enabled ? "Si" : "No");
        Serial.print("SSID: ");
        Serial.println(settings.wifiSettings.ssid_sta);

        memcpy(&previousSettings, &settings, sizeof(Settings));
    }
}

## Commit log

2018-09-19 Muecas tornillos y forma de la base
2018-09-20 Holes to support the base for connectors
2018-10-09 Pieza para USB y FTDI
2018-10-10 Modelo 3D embellecedor y soporte completado
    [WallBox_pieces.stl]
2018-10-10 Completed 3D parts
    [WallBox_pieces.skp]
2018-10-10 Exported 3D Parts to STL format
    [WallBox_pieces.stl]
2018-10-22 Changed readme
    [DomoticShutter.fzz]
2019-03-27 Reseted software and updated images
    [DomoticShutter.fzz, WallBox_pieces.skp, WallBox_pieces.stl]
2019-04-04 KiCAD project
    [Arduino_Pro_Mini.kicad_pcb, Arduino_Pro_Mini.sch]
2019-04-06 PCB terminada
    [Arduino_Pro_Mini.csv, Arduino_Pro_Mini.kicad_pcb, Arduino_Pro_Mini.sch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]
2019-04-08 Reducida tamaño PCB
    [Arduino_Pro_Mini.kicad_pcb, Arduino_Pro_Mini.sch]
2019-04-09 Soporte 3D para PCB
2019-04-26 huecos tornillos
    [huecos_tornillos.skp]
2019-05-16 Wireframe image
2019-07-03 Brass Inserts holes
2020-04-20 Schematic updated and code
    * Code is updated with a new finite state machine for LCD messages.
    * SoftwareSerial updated to support my own ISR
    * Buttons interrupts added
    * New schematic using the Relay approach
    * Kicad Own Libraries added
    [Arduino_Pro_Mini.csv, Arduino_Pro_Mini.kicad_pcb, Arduino_Pro_Mini.sch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]
2020-04-21 3V3 Power Module Library
    Added ESP and LCD connectors to schematic
    [DomoticShutterPanel.sch]
2020-04-24 Changed to radio approach
    [DomoticShutterPanel.kicad_pcb, DomoticShutterPanel.sch]
2020-04-28 Changed architecture to ESP8266 as master
    See documentation
    [DomoticShutterPanel.sch]
2020-06-16 lcd stm Diagram
    * lcd diagram nearly completed
    * Added new 3d library for arduino pro mini
    [DomoticShutterPanel.sch]
2020-08-08 Slave main functions completed
    - Roller shutter working
    - Buzzer working
    [Firmware_Arduino.ino, basic_defines.h]
2020-08-12 Added Jobmod, switch commands, suncalcs and getweather
    - Added Job mode
    - Added switch commands in slave and master
    - Added suncalculation library to get sun azimuth
    - Added a function getweatherData to get online data of the current weather
    - The system now store UTC time.
2020-08-27 EEPROM storing and UI completed
    Also a sketch in Processing was developed to test the UCD principles for the UI.
    [DomoticShutterPanel.sch]
2020-08-29 Updated 3D model to Crossed layout
    [DomoticShutterPanel.sch, WallBox_pieces.skp]
2020-08-29 Changed text labels
    [DomoticShutterPanel.sch]
2020-09-02 Added buzzer and 3d model updated
    [DomoticShutterPanel.kicad_pcb, DomoticShutterPanel.sch]
2020-09-16 Schematic cleanup and new 3d models
    3d models for S8550 and PS2701
    [DomoticShutterPanel.sch]
2020-09-17 Unified libraries to one
    [DomoticShutterPanel.sch]
2020-09-17 Pins slaved fixed and Serial messages debug
    [Firmware_Arduino.ino, Firmware_ESP8266.ino, basic_defines.h]
2020-09-17 Changed folder structure
    [DomoticShutterPanel.kicad_pcb, DomoticShutterPanel.sch, WallBox_pieces.skp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]
2020-09-21 Updated 3D models and schematic
    Arduino symbol changed in schematic. The UART connector is no longer displayed and I can be accessed externaly.
    New 3D models for 400mhz modules, buzzer and conectors.
    [DomoticShutterPanel.sch, WallBox_pieces.skp, huecos_tornillos.skp]
2020-09-26 Changed to SMD pushbutton
    [DomoticShutterPanel.kicad_pcb, DomoticShutterPanel.sch]
2020-09-27 R and C added for buttons
    [DomoticShutterPanel.kicad_pcb, DomoticShutterPanel.sch]
2020-10-02 Positioned all footprints
    [DomoticShutterPanel.kicad_pcb, DomoticShutterPanel.sch]
2020-10-02 New design rules
    [DomoticShutterPanel.kicad_pcb]
2020-10-03 Traced tracks
    [DomoticShutterPanel.kicad_pcb, DomoticShutterPanel.sch]
2020-10-05 Archived footprints
2020-10-05 Ready to production
    [DomoticShutterPanel.kicad_pcb, DomoticShutterPanel.sch]
2020-10-09 Renamed files
    [RollerShutterControlPanel.kicad_pcb, RollerShutterControlPanel.sch]
2023-08-24 Uses arduino CLI and github-action for compile
2023-08-24 Test compile-arduino-sketch on github actions
2023-08-28 Better error handling for lcd and wifi sta
    [Firmware_ESP8266.ino]
2023-09-06 Creation of AP if STA isn't available (AP features not implemented yet), better isolation of buttons API and a proper enter/idling/wakeup procedures.
2023-09-07 Wrong state change. Moved more items to esp8266_utils
    [ESP8266_Utils.h, Firmware_ESP8266.ino, basic_defines.h]
2023-09-10 Added Roller Shutter Control Panel Protocol (RSCP) for i2c communication stack protocol
2023-09-12 LowPower in AVR and proper button interrupts.
2025-07-21 Removed abusive use of ticker. Screen is now updated in main loop. Return to default menu after waking up if menu are not a shutter when there is a button timeout.
2025-07-25 keep adjust level if releasing button for less than 2 sconds when changing the time
2025-07-25 sound redesign and buttons ticker removed.
    [Firmware_ESP8266.ino, buttons.h, lcd.h]
2025-08-06 Feature menu wifi ssid (#12)
    * Wifi ssid
    * Safer eeprom scheduled writes
    * Some fixes given by copilot
    * better defines
    [ESP8266_Utils.h, Firmware_ESP8266.ino, basic_defines.h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]
2025-08-08 Feature menu wifi ssid (#13)
    * better encapsulation of pending configuration in lcd
    * Refactor WiFi settings and update handling; add able to disable/enable ble and display wifi/weater indication icon in screen
    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
    [ESP8266_Utils.h, Firmware_ESP8266.ino, basic_defines.h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]
2025-08-10 Fixed a bug with long real radio frame. Handle rscp errors.
    [Firmware_Arduino.ino, lcd.h, radioProtocol.h]
2025-08-31 New 3D printed part. Installed in site.

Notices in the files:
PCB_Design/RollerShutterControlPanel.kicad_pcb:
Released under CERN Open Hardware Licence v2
